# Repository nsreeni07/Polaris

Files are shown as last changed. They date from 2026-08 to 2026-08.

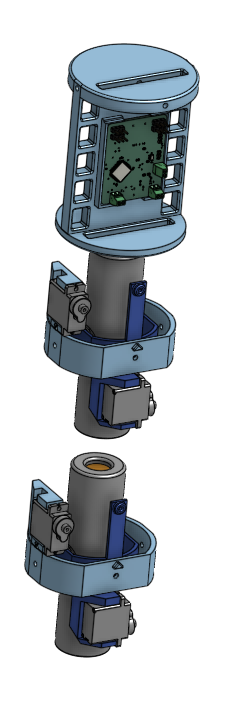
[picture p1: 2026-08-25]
Assets/Avionics and TVC.png

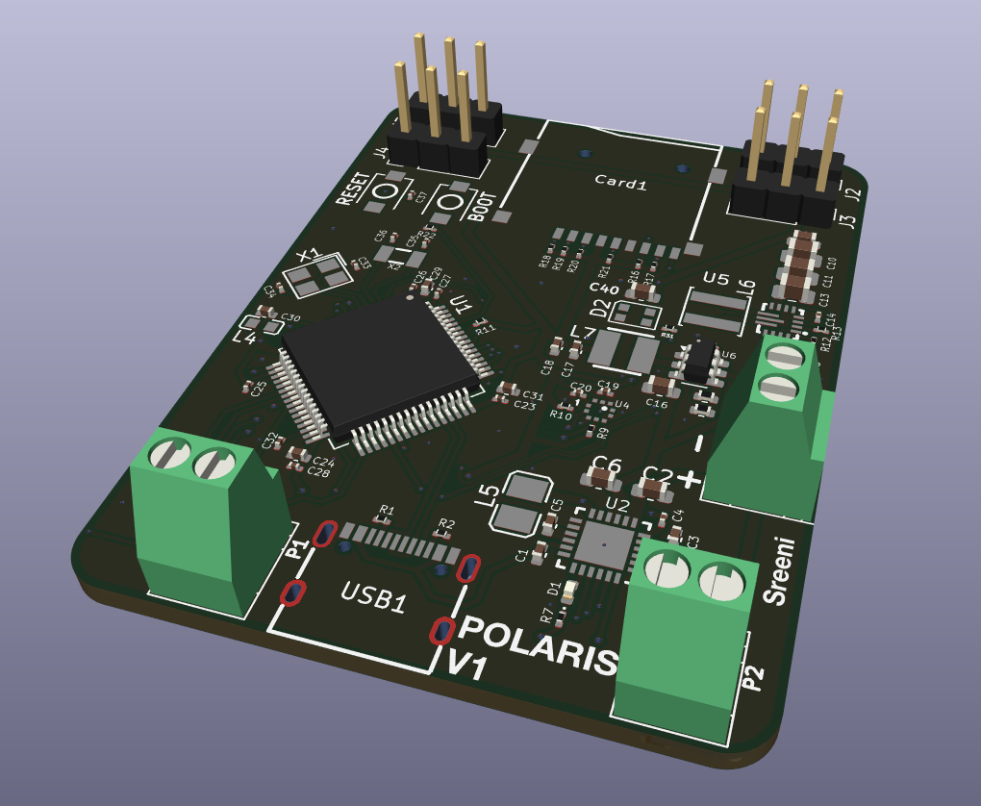
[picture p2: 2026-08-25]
Assets/Flight Computer PCB 3D.png

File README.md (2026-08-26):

# Polaris
Polaris is a two-stage amateur rocket with active thrust vector control(TVC) on the booster, along with a custom flight computer, ground support hardware, and firmware. 

# Why
Most amateur rocketry projects rely on passive stablization:fins,high-TWR motors. Polaris was built to go further. It has a ground lit booster stage with activle gimbal control instead of fins. Then after apogee the second motor lights hot-staging the booster stage off. Then paired with the flight computer the rocket stablizes and lands by itself

# Breakdown
Polaris is made up of 3 main subsystems
  1. Rocket-Airframe,Motors
  2. Flight Computer-Custom electronics and firmware that control the veichles orientation 
  3. Launchpad - the ground support equipment that holds, arms, and releases the rocket 

# Subsystems In Depth 
  1. Rocket
      - 2-Stage both with TVC 
      - 74cm length, 7.62 diameter, 662g dry mass
      - F-15 Motors 

  2. Flight Computer 
      - STM32F722RET6 MicroController
      - ICM-45686 IMU 
      - BMP580 Barometer
      - BQ25883 Battery Charger 
      - 4 channel servo PWM 
      - microSD Card for logging

  3. Launchpad 
      - ESP32 MicroController
      - 2 control arms that hold and release the rocket at liftoff 
      - 2 ESP32-CAM modules that record the launch 
      - RGB strip light and 4 2812 LEDs for pad status/lighting 
      - Water deluge system for pad deck 
      
  4. Firmware
  The flight computer is written from scratch organized into driver-level code (Core/) and mission appliccation logic (App/), covering the state machine, sensor fusion (Kalman filtering), pyro firing logic, servo/TVC Control, GPS parsing, DFU handoff, and the onboard     parameter store. Safety critical paths, particularly pyro firing, use redundant latching to prevent unintended actuation.  

  onshape Link: https://cad.onshape.com/documents/130dc36974a4df304d494706/w/43298f754d2d228858bc474d/e/d549df94310ea82951faf52f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
 # CAD 
Launchpad with Rocket
Rocket (2)
TVC Mount (2)

 # PCB


Flight Computer PCB 3D

|Category |Name |Price |Source |Purpose |FIELD6|Quantity|
|---|---|---|---|---|---|---|
|Electronics |ESP32 type-c FT232 |$4.60 |https://tinyurl.com/yhpx8n6v |MicroController for Launchpad | |1 |
| |ESP32 Expansion Board |$2.60 |https://tinyurl.com/23y7nzj4 |Expansion Board | |1 |
| |Esp32 Cam |$6.80 |https://tinyurl.com/4du8rxrx |Camera Board for recording | |1 |
| |WS2812 Breakout |$1.10 |https://tinyurl.com/47v776rm |Lights for Launchpad | |4 |
| |RGB Strip Light |$5.10 |https://tinyurl.com/364y65ux |Lights for Launchpad | |1 |
| |SG90 Servos |$9.00 |https://tinyurl.com/mr2s3xp6 |Servos for TVC and Launchpad Control Arms| |5 |
| |DRV8871 H-Bridge Motor Driver |$2.65 |https://tinyurl.com/32cf8wx4 |Motor Driver for Water Deluge System | |1 |
| |Jumper Wires |$4.70 |https://tinyurl.com/58u2vc35 |Wires | |1 |
| |22 AWG Wire |$3.39 |https://tinyurl.com/bdz5rad7 |Wires | |1 |
| |2.54mm Screw Terminal |$5.22 |https://tinyurl.com/4t54j69v |Screw Terminal | |2 |
| |JST XH2.54 Pitch 2 Pin Male Female|$2.29 |https://tinyurl.com/397bn54r |Battery Connector | |1 |
| |Micro SD Card |$7.70 |https://tinyurl.com/yx3v2jh6 |SD Card for Data logging | |1 |
| |OV5640 Camera |$5.47 |https://tinyurl.com/mv5eb5tb |Camera For recording | |1 |
| |DC Sumersible Pump |$2.43 |https://tinyurl.com/bp4uh89j |Water Pump | |1 |
| |2S Lipo |$4.60 |https://tinyurl.com/3x3pstst |Battery | |1 |
|Category |Name |Price |Source |Purpose | |Quantity|
|Hardware |3.00" Airframe Tubing |$14.16 |https://locprecision.com/products/cardboard-airframes?variant=39778656125119|Main Body Tube | |1 |
| |Hot Glue Sticks |$2.17 |https://tinyurl.com/yvwvy5t6 |Adhesive | |1 |
| |Epoxy |$3.42 |https://tinyurl.com/9rpxazkp |Adhesive | |1 |
| |Silicone Tube |$2.80 |https://tinyurl.com/3bzxhtnu |Tubing for Water Deluge System | |1 |
| |Header Pins |$3.63 |https://tinyurl.com/u3jnrvzz |Header Pins | |4 |
| | | | | | | |
|Below Totals contain Tax and Shipping | | | | | | |
| | | | | | | |
|LCSC |$105.00 |(PCB Parts| | | | |
|JLCPCB |$33.00 |(Bare PCB)| | | | |
|Aliexpress Total |$114.67 | | | | | |
|LOC Total |$28.30 | | | | | |
| | | | | | | |
| | | | | | | |
|Grant Total: |$280.97 | | | | | |

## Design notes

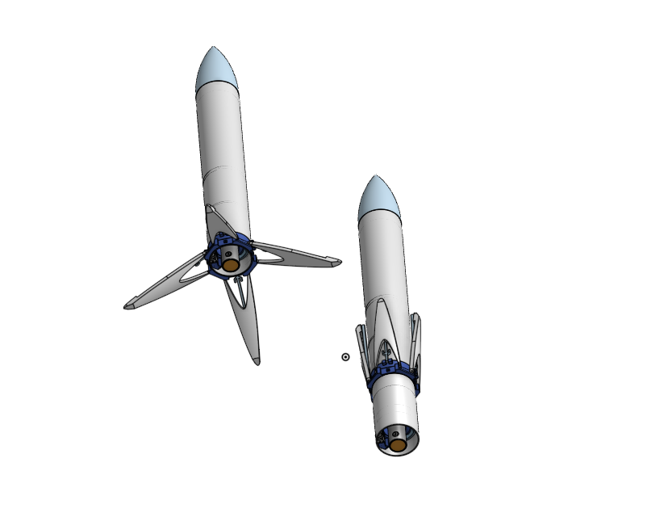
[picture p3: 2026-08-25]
Assets/Rocket.png

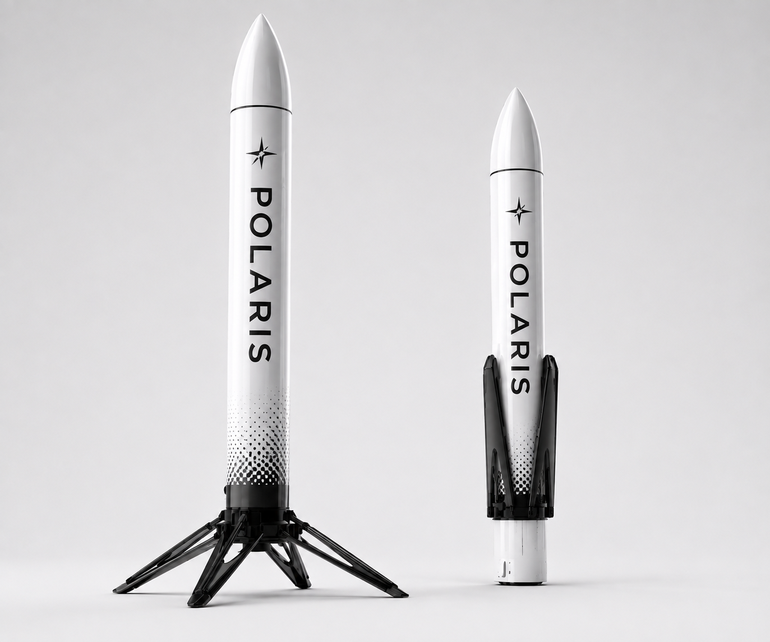
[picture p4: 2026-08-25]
Assets/Polaris Render.png

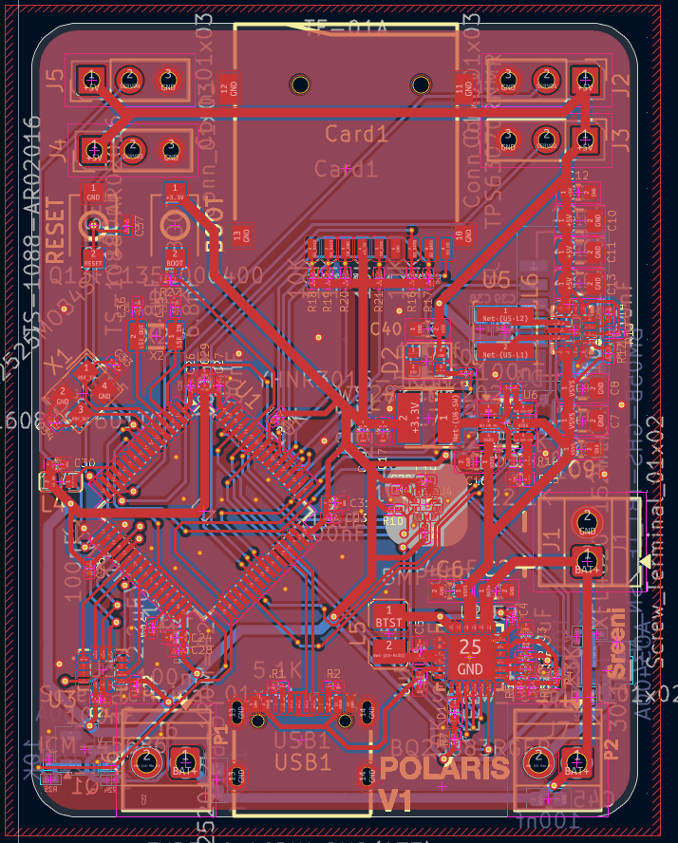
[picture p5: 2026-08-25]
Assets/Flight Computer PCB.png

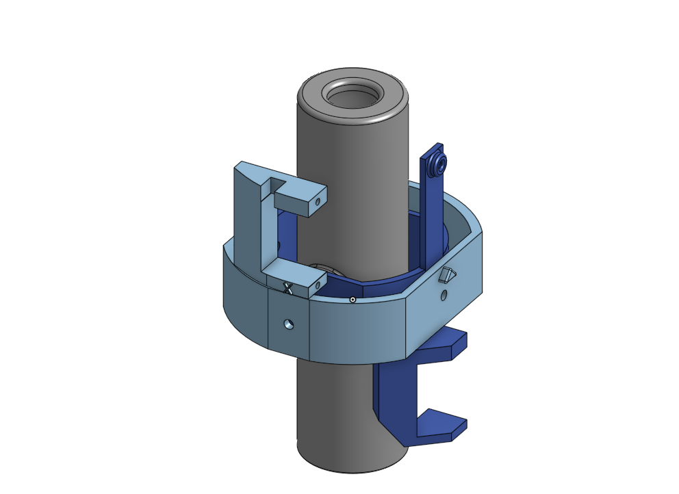
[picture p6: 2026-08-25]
Assets/TVC Mount.png

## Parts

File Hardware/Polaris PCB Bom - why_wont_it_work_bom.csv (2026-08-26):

Designator | Footprint | Quantity | Value | LCSC Part # | Link
BOOT, RESET | SW-SMD_L3.9-W3.0-P4.45 | 2 | TS-1088-AR02016 | C720477 | https://www.lcsc.com/product-detail/C720477.html?s_z=n_q_TS-1088-AR02016
C1, C28, C29, C30 | 402 | 4 | 1uF |  | https://www.lcsc.com/product-detail/C52923.html?s_z=n_q_CL05A105KA5NQNC
C10, C11, C13 | 805 | 3 | 22uF |  | https://www.lcsc.com/product-detail/C45783.html?s_z=n_q_CL21A226MAQNNNE
C12, C2, C38, C9 | 603 | 4 | 10uF |  | https://www.lcsc.com/product-detail/C19702.html?s_z=n_q_CL10A106KP8NNNC
C14, C15, C19, C20, C21, C22, C23, C24, C25, C26, C27, C37 | 201 | 12 | 100nF |  | https://www.lcsc.com/product-detail/C76934.html?s_z=n_q_GRM033R61A104KE15D
C16 | 603 | 1 | 2.2uF |  | https://www.lcsc.com/product-detail/C23630.html?s_z=n_q_CL10A225KO8NNNC
C17, C18 | 402 | 2 | 22uF |  | https://www.lcsc.com/product-detail/C415703.html?s_z=n_q_GRM155R60J226ME11D
C3, C31, C5 | 402 | 3 | 10uF |  | https://www.lcsc.com/product-detail/C15525.html?s_z=n_q_CL05A106MQ5NUNC
C32 | 201 | 1 | 2.2uF |  | https://www.lcsc.com/product-detail/C319184.html?s_z=n_q_2.2uF%252010V%2520X5R%25200201
C33, C34 | 201 | 2 | 20pF |  | https://www.lcsc.com/product-detail/C325444.html?s_z=n_q_CC0201JRNPO9BN200
C35, C36 | 201 | 2 | 6.8pF |  | https://www.lcsc.com/product-detail/C85916.html?s_z=n_q_GRM0335C1H6R8CA01D
C39, C40, C41, C45, C46 | 603 | 5 | 100nf |  | https://www.lcsc.com/product-detail/C14663.html?s_z=n_q_CC0603KRX7R9BB104
C4 | 201 | 1 | 47nF |  | https://www.lcsc.com/product-detail/C505465.html?s_z=n_q_CC0201KRX5R7BB473
C6 | 603 | 1 | 44uF |  | https://www.lcsc.com/product-detail/C3794525.html?s_z=n_q_44%2520uF
C7, C8 | 805 | 2 | 10uF |  | https://www.lcsc.com/product-detail/C440198.html?s_z=n_q_GRM21BR61H106KE43L
CARD1 | TF-SMD_TF-01A | 1 | TF-01A | C91145 | https://www.lcsc.com/product-detail/C2889258.html?s_z=n_q_TF-01A
D1 | 402 | 1 | LED |  | https://www.lcsc.com/product-detail/C965793.html?s_z=n_q_XL-1005UGC
D2 | LED_WS2812B-2020_PLCC4_2.0x2.0mm | 1 | WS2812B-2020 |  | https://www.aliexpress.us/item/3256812215746950.html?curPageLogUid=OtKo3ZWj1teS
J1, J6, J7 | TerminalBlock_Xinya_XY308-2.54-2P_1x02_P2.54mm_Horizontal | 3 | Screw_Terminal_01x02 |  | https://tinyurl.com/4t54j69v
J2, J3, J4, J5 | PinHeader_1x03_P2.54mm_Vertical | 4 | Conn_01x03 |  | https://tinyurl.com/u3jnrvzz
J8 | JST_BM05B-GHS-TBT_LF__SN__N_ | 1 | BM05B-GHS-TBT_LF__SN__N_ |  | https://tinyurl.com/397bn54r
L4 | L0603 | 1 | FCM1608KF-601T03 | C141723 | https://www.lcsc.com/product-detail/C141723.html?s_z=n_q_FCM1608KF-601T03
L5 | L2520 | 1 | DFE252012F-1R0M=P2 | C435392 | https://www.lcsc.com/product-detail/C435392.html?s_z=n_q_DFE252012F-1R0M%253DP2
L6 | IND-SMD_L4.0-W4.0-A | 1 | XFL4020-152MEC | C3033018 | https://www.lcsc.com/product-detail/C3033018.html?s_z=n_q_XFL4020-152MEC
L7 | IND-SMD_L3.0-W3.0 | 1 | YHNR3015-5R6M | C18236327 | https://www.lcsc.com/product-detail/C18236327.html?s_z=n_q_YHNR3015-5R6M
Q1, Q2 | SOT-23 | 2 | AO3400A |  | https://www.lcsc.com/product-detail/C20917.html?s_z=n_q_p_Transistor_FET%253AAO3400A
R1, R2 | 201 | 2 | 5.1K |  | https://www.lcsc.com/product-detail/C270344.html?s_z=n_q_0201WMF5101TEE
R10, R11, R12, R13, R16, R17, R18, R19, R20, R21, R22, R23, R26, R28, R30, R6, R7, R8, R9 | 201 | 19 | 10K |  | https://www.lcsc.com/product-detail/C7467266.html?s_z=n_q_FRC0201J103%2520TS
R14 | 402 | 1 | 100K |  | https://www.lcsc.com/product-detail/C25741.html?s_z=n_q_0402WGF1003TCE
R15 | 402 | 1 | 22.1K |  | https://www.lcsc.com/product-detail/C43473.html?s_z=n_q_0402WGF2212TCE
R24, R29 | 201 | 2 | 100K |  | https://www.lcsc.com/product-detail/C60491.html?s_z=n_q_t_100K
R25, R27, R31 | 201 | 3 | 100 |  | https://www.lcsc.com/product-detail/C304499.html?s_z=n_q_RC-01W1000FT
R3 | 201 | 1 | .383k |  | https://www.lcsc.com/product-detail/C166212.html?s_z=n_q_RTT013833FTH
R4 | 201 | 1 | 5.23K |  | https://www.lcsc.com/product-detail/C423492.html
R5 | 201 | 1 | 30.1K |  | https://www.lcsc.com/product-detail/C273278.html?s_z=n_q_RC0201FR-0730K1L
U1 | LQFP-64_10x10mm_P0.5mm | 1 | STM32F722RETx |  | https://www.lcsc.com/product-detail/C118207.html?s_z=n_q_STM32F722RET6
U2 | VFQFPN-24_L4.0-W4.0-P0.50-BL-EP2.8 | 1 | BQ25883RGER | C544362 | https://www.lcsc.com/product-detail/C544362.html?s_z=n_q_BQ25883RGER
U3 | LGA-14_L3.0-W2.5-P0.50-TL | 1 | ICM-45686 | C22459454 | https://www.lcsc.com/product-detail/C22459454.html?s_z=n_q_ICM-45686
U4 | LGA-10_L2.0-W2.0-P0.50-TL_BMP580 | 1 | BMP580 | C22391138 | https://www.lcsc.com/product-detail/C22391138.html?s_z=n_q_BMP580
U5 | VQFN-HR-15_L3.0-W2.5-P0.50-BL_TPS63070RNMR | 1 | TPS63070RNMR | C109322 | https://www.lcsc.com/product-detail/C109322.html?s_z=n_q_TPS63070RNMR
U6 | SOT-23-6 | 1 | LMR51430 |  | https://www.lcsc.com/product-detail/C5219261.html?s_z=n_q_LMR51430YFDDCR
USB1 | USB-C-SMD_TYPE-C-6PIN-2MD-073 | 1 | TYPE-C 16PIN 2MD(073) | C2765186 | https://www.lcsc.com/product-detail/C2765186.html?s_z=n_q_TYPE-C%252016PIN%25202MD%28073%29
X1 | CRYSTAL-SMD_4P-L3.2-W2.5-BL | 1 | X322525MOB4SI | C9006 | https://www.lcsc.com/product-detail/C9006.html?s_z=n_q_X322525MOB4SI
X2 | FC-135R_L3.2-W1.5 | 1 | Q13FC1350000400 | C32346 | https://www.lcsc.com/product-detail/C32346.html?s_z=n_q_Q13FC13500004

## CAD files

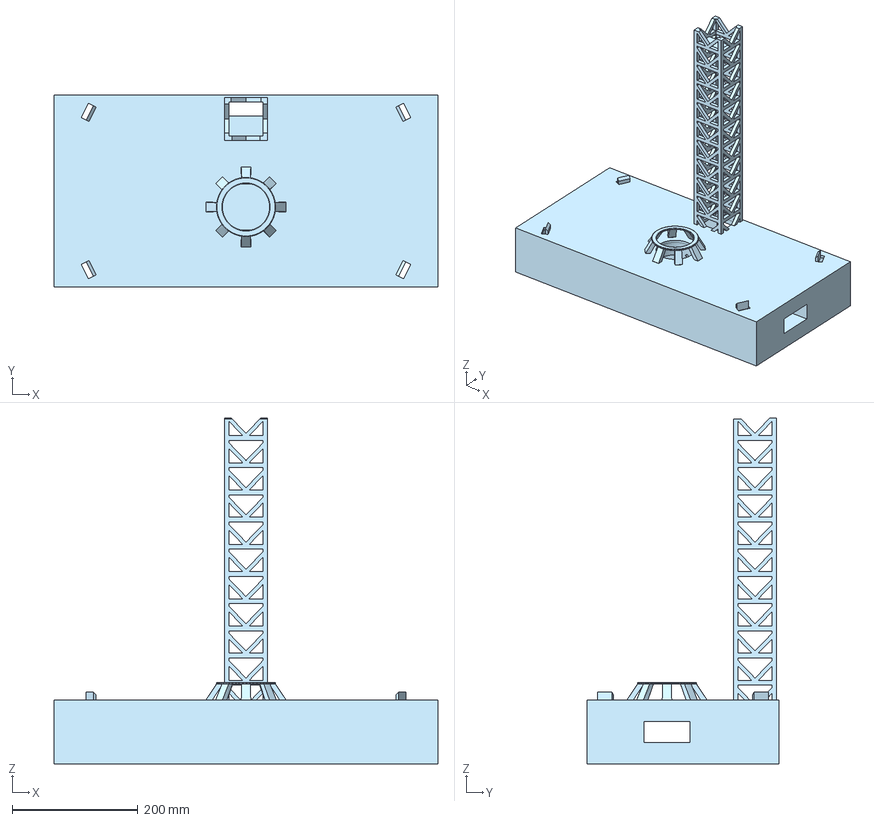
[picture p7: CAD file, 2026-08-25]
CAD/.step/Launchpad/Main Structure.step
609.6 x 304.8 x 549.2 mm

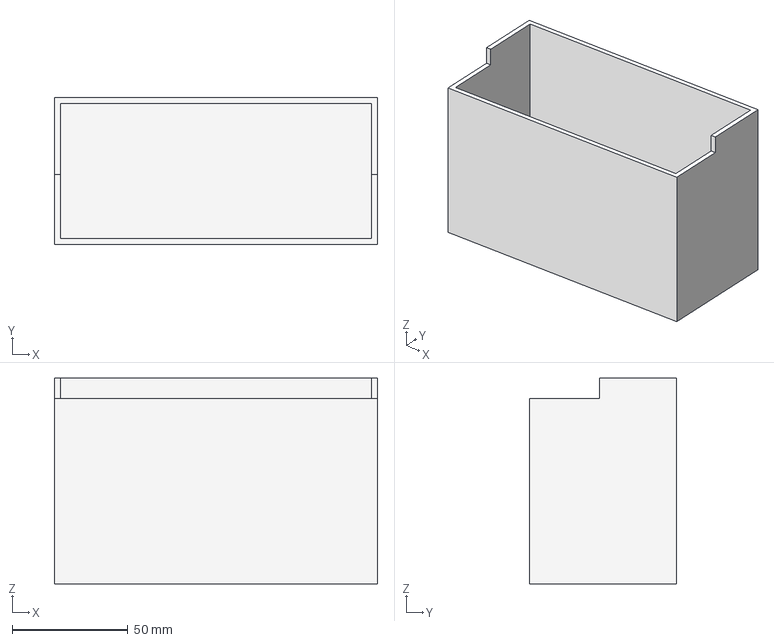
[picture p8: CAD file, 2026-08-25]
CAD/.step/Launchpad/Electronics Box.step
139.7 x 63.5 x 88.9 mm

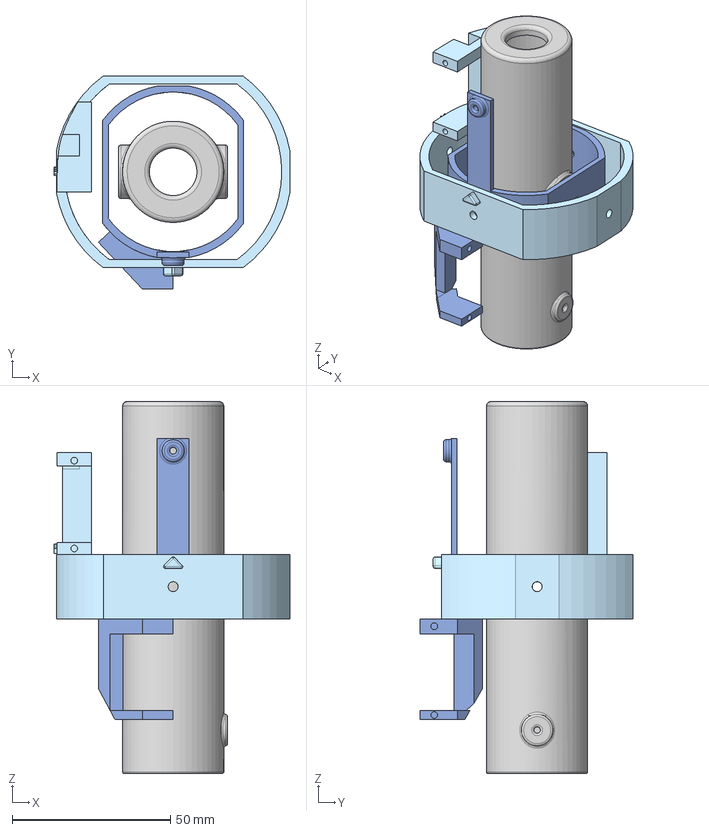
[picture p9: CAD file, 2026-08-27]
CAD/.step/Rocket/TVC Mount.step
74.4 x 67.3 x 117.5 mm

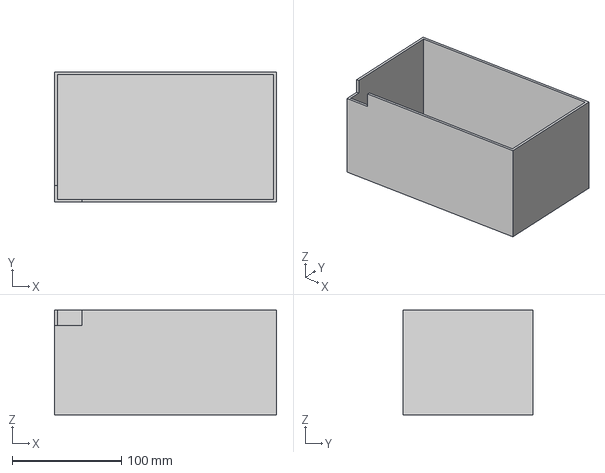
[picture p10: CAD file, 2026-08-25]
CAD/.step/Launchpad/Water Tank.step
203.2 x 119.4 x 96.0 mm

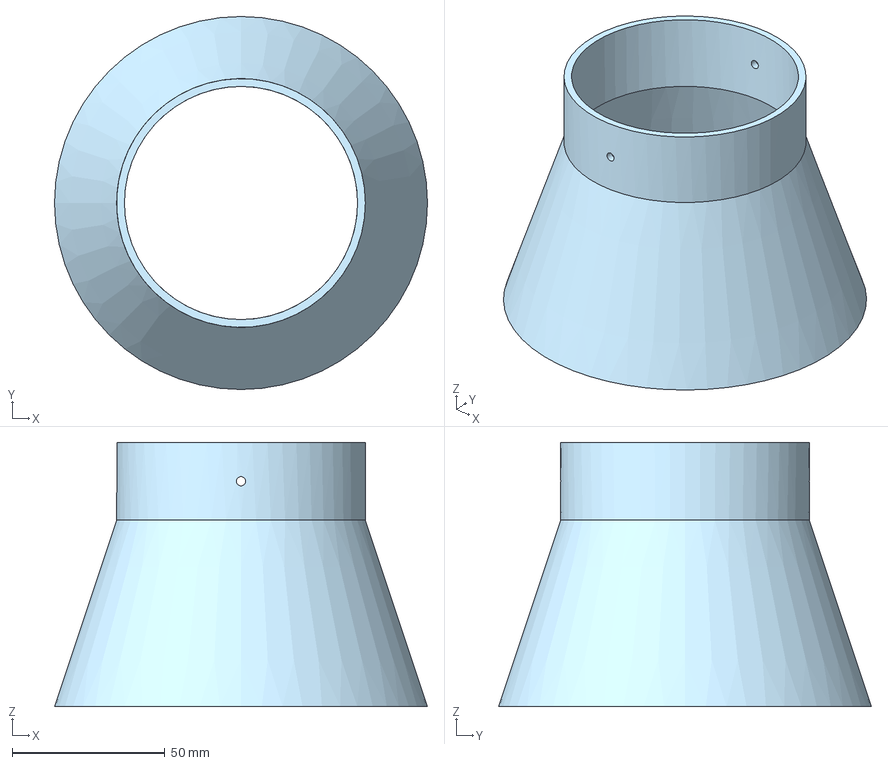
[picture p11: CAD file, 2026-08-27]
CAD/.step/Rocket/TVC Mount Test - Part 1.step
121.9 x 121.9 x 86.4 mm

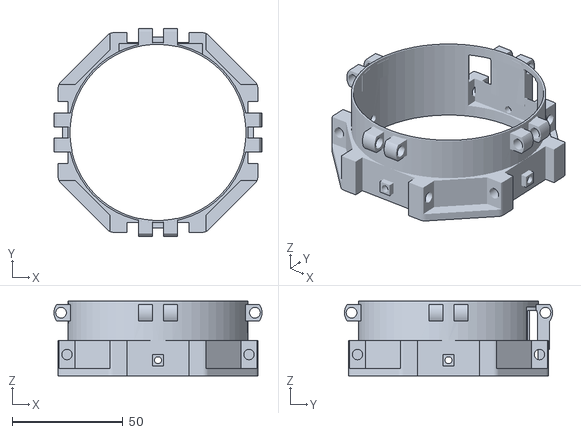
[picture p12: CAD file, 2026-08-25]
CAD/.stl/Rocket/Landing Mount.stl
93.7 x 93.7 x 33.8

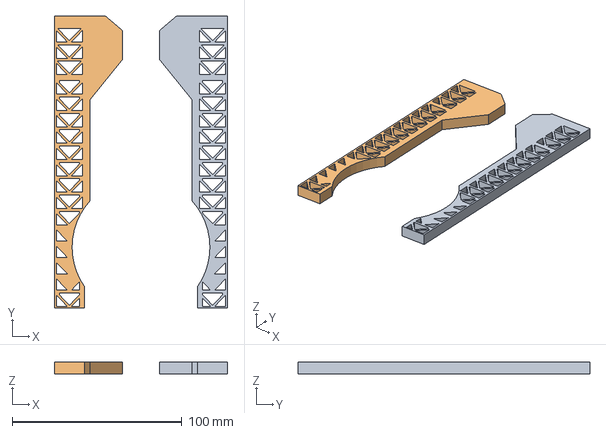
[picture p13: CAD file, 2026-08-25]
CAD/.step/Launchpad/Control Arms.step
102.3 x 172.2 x 7.11 mm

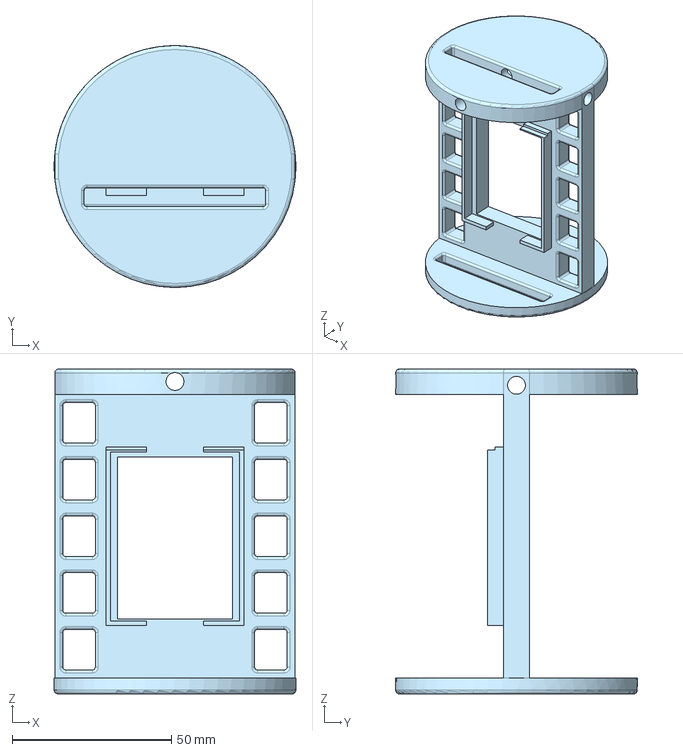
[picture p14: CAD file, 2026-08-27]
CAD/.step/Rocket/Avionics Bay.step
75.8 x 75.8 x 101.9 mm

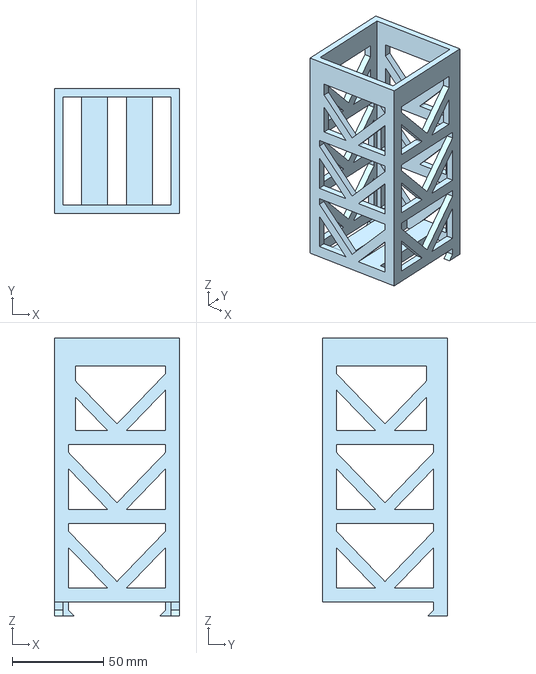
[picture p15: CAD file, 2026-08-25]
CAD/.step/Launchpad/Top Structure.step
68.6 x 68.6 x 152.4 mm

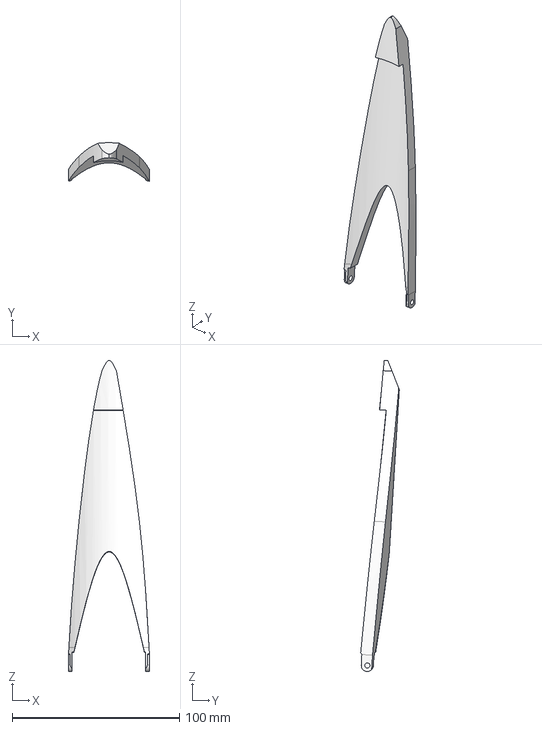
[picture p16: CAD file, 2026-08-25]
CAD/.step/Rocket/Landing Leg.step
48.3 x 23.1 x 185.8 mm

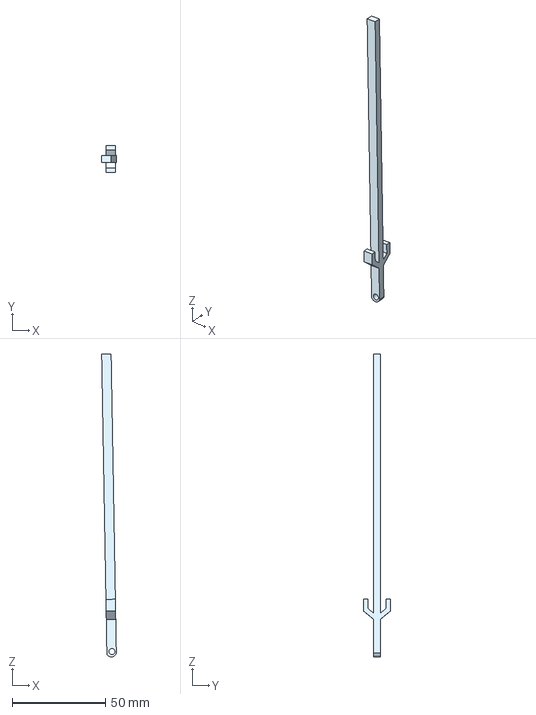
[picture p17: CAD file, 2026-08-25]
CAD/.step/Rocket/Landing Strut.step
7.87 x 14.5 x 162.2 mm

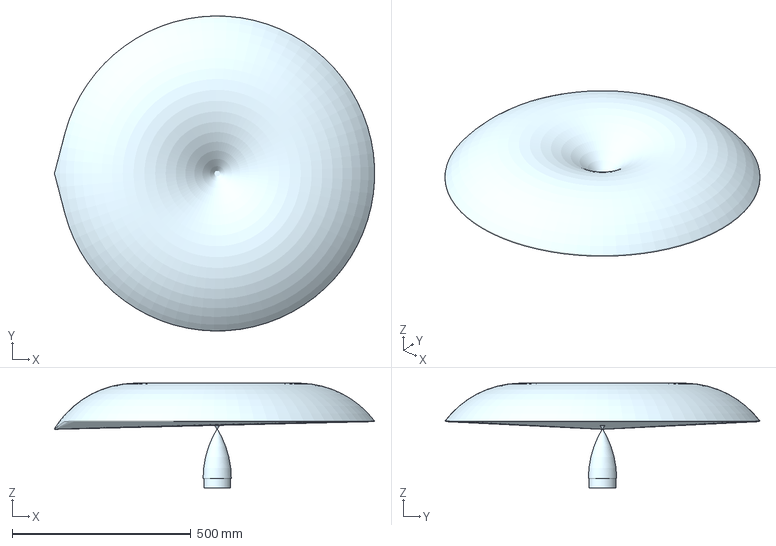
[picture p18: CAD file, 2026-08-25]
CAD/.step/Rocket/Nose Cone.step
895.6 x 881.2 x 292.6 mm

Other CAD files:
CAD/.stl/Rocket/TVC.stl
CAD/.stl/Launchpad/Control Arms.stl
CAD/.stl/Launchpad/Electronics Box.stl
CAD/.stl/Launchpad/Main Structure.stl
CAD/.stl/Launchpad/Top Structure.stl
CAD/.stl/Launchpad/Water Tank.stl
CAD/.stl/Rocket/Avionics Bay.stl
CAD/.stl/Rocket/Landing Leg.stl
CAD/.stl/Rocket/Nose Cone.stl
CAD/.stl/Rocket/TVC Mount Test - Part 1.stl

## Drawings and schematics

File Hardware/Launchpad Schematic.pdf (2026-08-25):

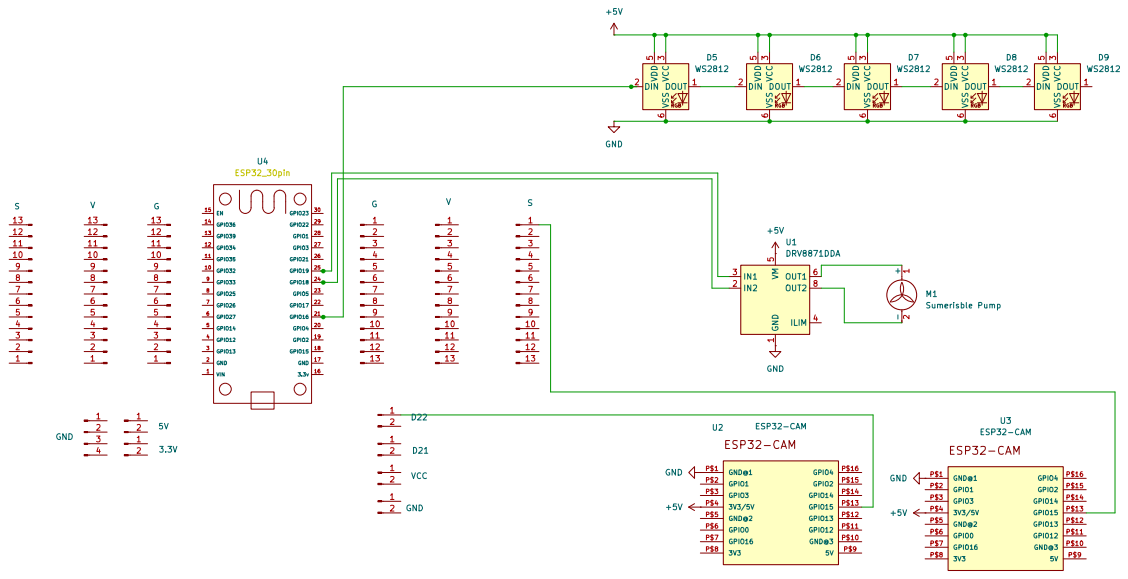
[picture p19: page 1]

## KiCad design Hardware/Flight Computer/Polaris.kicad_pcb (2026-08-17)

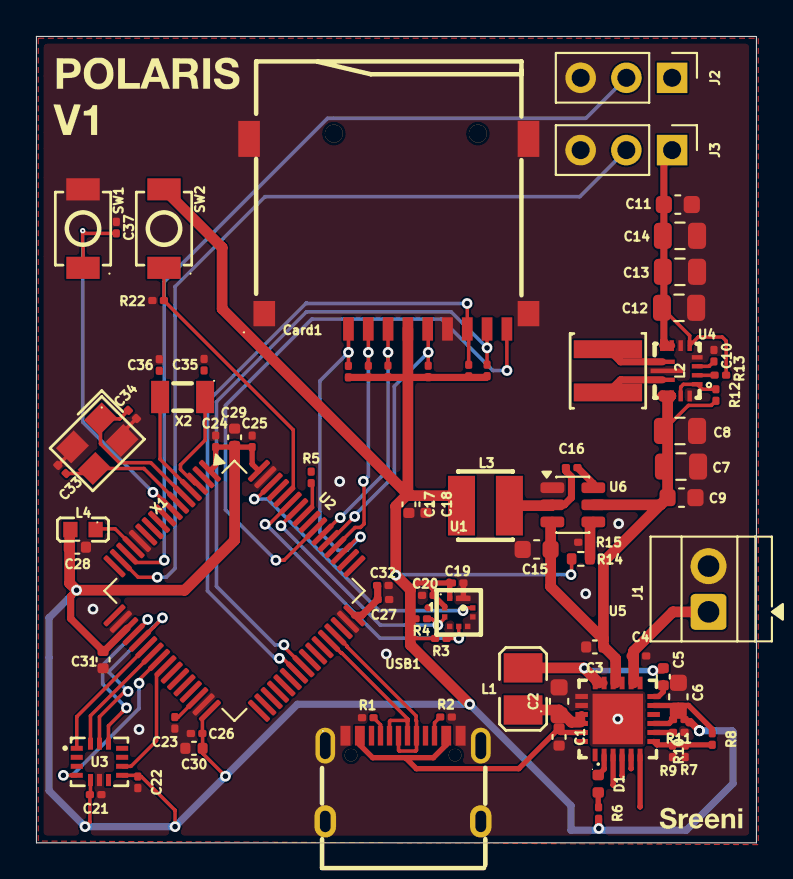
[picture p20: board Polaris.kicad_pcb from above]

Board: 2 copper layers, 40.0 x 44.8 mm, 79 parts (0 on the bottom side), 55 nets.

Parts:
C1, C29, C30, C31: 1uF; C_0402_1005Metric
C2, C6, C9, C11: 10uF; C_0603_1608Metric
C3: 44uF; C_0402_1005Metric
C4, C32: 10uF; C_0201_0603Metric
C5: 47nF; C_0402_1005Metric
C7, C8: 10uF; C_0805_2012Metric
C10, C16, C19, C20, C21, C22, C24, C25, C26, C27, C37: 100nF; C_0201_0603Metric
C12, C13, C14: 22uF; C_0805_2012Metric
C15: 2.2uF; C_0603_1608Metric
C17, C18: 22uF; C_0402_1005Metric
C23: 2.2uF; C_0201_0603Metric
C28: 100nF; C_0402_1005Metric
C33, C34: 20pF; C_0201_0603Metric
C35, C36: 6.8pF; C_0201_0603Metric
Card1: TF-01A; TF-SMD_TF-01A
D1: LED; LED_0402_1005Metric
J1: Screw_Terminal_01x02; TerminalBlock_Xinya_XY308-2.54-2P_1x02_P2.54mm_Horizontal
J2, J3: Conn_01x03; PinHeader_1x03_P2.54mm_Vertical
L1: 1uH; L2520
L2: 1.5uH; IND-SMD_L4.0-W4.0-A
L3: 5.6uH; IND-SMD_L3.0-W3.0
L4: FCM1608KF-601T03; L0603
R1, R2: 5.1k; R_0201_0603Metric
R3, R4, R5, R6, R7, R11, R12, R13, R16, R17, R18, R19, R20, R21, R22: 10K; R_0201_0603Metric
R8: 5.23K; R_0201_0603Metric
R9: 30.1K; R_0201_0603Metric
R10: 383; R_0201_0603Metric
R14: 100K; R_0402_1005Metric
R15: 22.1K; R_0201_0603Metric
SW1, SW2: TS-1088-AR02016; SW-SMD_L3.9-W3.0-P4.45
U1: BMP580; LGA-10_L2.0-W2.0-P0.50-TL_BMP580
U2: STM32F722RETx; LQFP-64_10x10mm_P0.5mm
U3: ICM-45686; LGA-14_L3.0-W2.5-P0.50-TL
U4: TPS63070RNMR; VQFN-15_L3.0-W2.5-P0.50-BL
U5: BQ25883RGER; VFQFPN-24_L4.0-W4.0-P0.50-BL-EP2.8
U6: LMR51430; SOT-23-6
USB1: TYPE-C 16PIN 2MD; USB-C-SMD_TYPE-C-16PIN-2MD-073
X1: X322525MOB4SI; CRYSTAL-SMD_4P-L3.2-W2.5-BL
X2: Q13FC1350000400; FC-135R_L3.2-W1.5

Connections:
+3.3V: C17.1, C18.1, C19.1, C20.1, C21.1, C22.1, C24.1, C25.1, C26.1, C27.1, C28.1, C29.1, C30.1, C31.1, C32.1, Card1.4 (VDD), L3.2, L4.2, R3.1, R4.1, R5.1, R6.2, R11.1, R14.1, R16.1, R17.1, R18.1, R19.1, R20.1, R21.1, SW2.1, U1.1 (VDDIO), U1.10 (VDD), U2.1 (VBAT), U2.19 (VDD), U2.32 (VDD), U2.48 (VDD), U2.64 (VDD), U3.5 (VDDIO), U3.8 (VDD)
+5V: C11.1, C12.1, C13.1, C14.1, J2.1, J3.1, R13.2, U4.5 (FB), U4.7 (Vout), U4.8 (Vout)
/BMP_INT: U1.7 (INT), U2.62 (PB9)
/BOOT: R22.1, SW2.2, U2.60 (BOOT0)
/BQ_CE: U2.61 (PB8), U5.3 (~CE)
/BQ_INT: R5.2, U2.57 (PB5), U5.6 (~INT)
/BQ_PG: R11.2, U5.9 (~PG)
/BTST: C5.1, L1.2, U5.17 (SW), U5.18 (SW)
/HSE_IN: C34.1, U2.5 (PH0), X1.1 (OSC1)
/HSE_OUT: C33.1, U2.6 (PH1), X1.3 (OSC2)
/I2C_SCL: R4.2, U1.2 (SCK), U2.58 (PB6), U5.5 (SCL)
/I2C_SDA: R3.2, U1.4 (SDI), U2.59 (PB7), U5.4 (SDA)
/ICM_CS: U2.20 (PA4), U3.12 (AP_CS)
/ICM_INT1: U2.24 (PC4), U2.41 (PA8), U3.4 (INT1/INT)
/ICM_INT2: U2.25 (PB0), U2.42 (PA9), U3.9 (INT2/FSYNC/CLKIN)
/ICM_SCK: U2.21 (PA5), U3.13 (AP_SCL/AP_SCLK)
/ICM_SDI: U2.23 (PA7), U3.14 (AP_SDA/AP_SDIO/AP_SDI)
/ICM_SDO: U2.22 (PA6), U3.1 (AP_SDO/AP_AD0)
/LSE_IN: C35.1, U2.3 (PC14), X2.1
/LSE_OUT: C36.1, U2.4 (PC15), X2.2
/RESET: C37.2, SW1.2, U2.7 (NRST)
/SD_CD: Card1.9 (CD), U2.55 (PB3)
/SD_CLK: Card1.5 (CLK(SCLK)), R21.2, U2.53 (PC12)
/SD_CMD: Card1.3 (CMD(DI)), R16.2, U2.54 (PD2)
/SD_DAT0: Card1.7 (DAT0(D0)), R20.2, U2.39 (PC8)
/SD_DAT1: Card1.8 (DAT1(RSV)), R19.2, U2.40 (PC9)
/SD_DAT2: Card1.1 (DAT2(RSV)), R18.2, U2.51 (PC10)
/SD_DAT3: Card1.2 (CDDAT3(CS)), R17.2, U2.52 (PC11)
/SERVO1: J2.2, U2.14 (PA0)
/SERVO2: J3.2, U2.15 (PA1)
/USB_DN: U2.44 (PA11), USB1.A7 (Dn1), USB1.B7 (Dn2)
/USB_DP: U2.45 (PA12), USB1.A6 (Dp1), USB1.B6 (Dp2)
BAT+: C4.1, J1.1, U5.13 (BAT), U5.14 (BAT)
GND: C1.2, C2.2, C3.2, C4.2, C6.2, C7.2, C8.2, C9.2, C10.1, C11.2, C12.2, C13.2, C14.2, C15.2, C17.2, C18.2, C19.2, C20.2, C21.2, C22.2, C23.2, C24.2, C25.2, C26.2, C27.2, C28.2, C29.2, C30.2, C31.2, C32.2, C33.2, C34.2, C35.2, C36.2, C37.1, Card1.6 (VSS), Card1.10 (GND), Card1.11 (GND), Card1.12 (GND), Card1.13 (GND), J1.2, J2.3, J3.3, R1.1, R2.1, R7.2, R9.2, R10.1, R15.2, R22.2, SW1.1, U1.3 (VSS), U1.5 (SDO), U1.6 (CSB), U1.8 (VSS), U1.9 (VSS), U2.12 (VSSA), U2.18 (VSS), U2.31 (VSS), U2.47 (VSS), U2.63 (VSS), U3.6 (GND), U4.4 (GND), U4.6 (FB2), U4.10 (PGND), U4.15 (Vsel), U5.19 (GND), U5.20 (GND), U5.25 (EP), U6.1 (GND), USB1.13 (EH), USB1.14 (EH), USB1.A1B12 (GND), USB1.B1A12 (GND), X1.2 (GND), X1.4 (GND)
unnamed: C2.1, L1.1, U5.21 (PMID), U5.22 (PMID)
unnamed: D1.2 (A), R6.1
unnamed: D1.1 (K), U5.2 (STAT)
unnamed: C23.1, U2.30 (VCAP_1)
unnamed: L4.1, U2.13 (VDDA)
unnamed: R12.1, U4.1 (PS/SYNC), U4.14 (EN)
unnamed: L2.2, U4.11 (L1)
unnamed: L2.1, U4.9 (L2)
unnamed: R13.1, U4.2 (PG)
unnamed: C10.2, U4.3 (Vaux)
unnamed: C5.2, U5.12 (BTST)
unnamed: R10.2, U5.8 (ILIM)
unnamed: R7.1, R8.2, R9.1, U5.7 (TS)
unnamed: C16.2, U6.6 (CB)
unnamed: R14.2, R15.1, U6.4 (FB)
unnamed: C16.1, L3.1, U6.2 (SW)
unnamed: R1.2, USB1.A5 (CC1)
unnamed: R2.2, USB1.B5 (CC2)
VBUS: C1.1, U5.23 (VBUS), USB1.A4B9 (VBUS), USB1.B4A9 (VBUS)
VREGN: C6.1, R8.1, U5.11 (REGN)
VSYS: C3.1, C7.1, C8.1, C9.1, C15.1, R12.2, U4.12 (Vin), U4.13 (Vin), U5.15 (SYS), U5.16 (SYS), U6.3 (VIN), U6.5 (EN)

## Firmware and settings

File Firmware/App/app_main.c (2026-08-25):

/* no way jose */
#include "board.h"
#include "app_config.h"
#include "app_types.h"
#include "app_main.h"

#include "imu_icm45686.h"
#include "baro_bmp580.h"
#include "servo.h"
#include "pyro.h"
#include "ahrs.h"
#include "kalman.h"
#include "tvc_control.h"
#include "flight_state.h"
#include "datalog.h"
#include "param_store.h"
#include "safety.h"

#if ENABLE_CHARGER
#include "charger_bq25883.h"
#endif
#if ENABLE_GPS
#include "gps_nmea.h"
#endif
#if ENABLE_STATUS_LED
#include "status_led.h"
#endif

static uint32_t s_last_ctrl_ms, s_last_baro_ms, s_last_cont_ms, s_last_flush_ms;
#if ENABLE_CHARGER
static uint32_t s_last_charger_ms;
static uint16_t s_last_vbat_mv;
#endif
#if ENABLE_STATUS_LED
static uint32_t s_last_led_ms;
#endif

void app_init(void)
{
    pyro_init();

#if ENABLE_STATUS_LED
    led_init();
    led_show_state(ST_INIT);
#endif

    servo_init();
    servo_center_all();

    int imu_rc = imu_init();
    int baro_rc = baro_init();
#if ENABLE_CHARGER
    charger_init();
#endif
#if ENABLE_GPS
    gps_init();
#endif

    params_t params;
    param_load(&params);
    tvc_set_gains(params.tvc_kp, params.tvc_ki, params.tvc_kd);

    ahrs_init();
    kalman_init();
    tvc_init();

    if (imu_rc == 0)
        imu_calibrate_gyro();
    if (baro_rc == 0)
        baro_zero();

    int log_rc = datalog_init();
    (void)log_rc;

    safety_init();   /* starts IWDG - call last */

    fsm_init();
#if ENABLE_STATUS_LED
    led_show_state(ST_GROUND_IDLE);
#endif
}

static void run_control_tick(void)
{
    if (!g_imu_data_ready)
        return;

    static uint32_t last_t_ms = 0;
    imu_sample_t s;
    if (imu_read(&s) != 0)
        return;

    float dt_s = (last_t_ms == 0) ? (1.0f / CTRL_HZ) : (float)(s.t_ms - last_t_ms) / 1000.0f;
    last_t_ms = s.t_ms;

    ahrs_update(&s, dt_s);

    float axial_g;
    switch (ARM_UP_AXIS) {
        case 0: axial_g = s.ax; break;
        case 1: axial_g = s.ay; break;
        default: axial_g = s.az; break;
    }
    axial_g *= ARM_UP_SIGN;
    float axial_accel_ms2 = (axial_g - 1.0f) * 9.80665f;
    kalman_predict(axial_accel_ms2, dt_s);

    fsm_tick(&s, dt_s);

    wdg_refresh();
}

void app_loop(void)
{
    for (;;) {
        uint32_t now = HAL_GetTick();

        if ((now - s_last_ctrl_ms) >= (1000u / CTRL_HZ)) {
            s_last_ctrl_ms = now;
            run_control_tick();
        }

        if ((now - s_last_baro_ms) >= (1000u / BARO_HZ)) {
            s_last_baro_ms = now;
            float alt, temp;
            if (baro_read(&alt, &temp) == 0)
                kalman_correct_baro(alt);
        }

        if ((now - s_last_cont_ms) >= (1000u / CONT_HZ)) {
            s_last_cont_ms = now;
            /* ground-status display only; pyro_fire() re-checks continuity itself */
        }

#if ENABLE_CHARGER
        if ((now - s_last_charger_ms) >= (1000u / CHARGER_HZ)) {
            s_last_charger_ms = now;
            charger_read_vbat_mv(&s_last_vbat_mv);
            g_fsm.snapshot.vbat_mv = s_last_vbat_mv;
        }
#endif

#if ENABLE_STATUS_LED
        if ((now - s_last_led_ms) >= (1000u / LED_HZ)) {
            s_last_led_ms = now;
            led_show_state(fsm_get_state());
        }
#endif

        if ((now - s_last_flush_ms) >= LOG_FLUSH_MS) {
            s_last_flush_ms = now;
            datalog_flush();
        }

#if ENABLE_GPS
        gps_poll();
#endif

        static uint32_t last_log_ms = 0;
        if ((now - last_log_ms) >= (1000u / LOG_RATE_HZ)) {
            last_log_ms = now;
            log_record_t rec = {0};
            rec.magic = LOG_RECORD_MAGIC;
            rec.state = (uint8_t)g_fsm.state;
            rec.t_ms = g_fsm.snapshot.t_ms;
            rec.ax = g_fsm.snapshot.imu.ax;
            rec.ay = g_fsm.snapshot.imu.ay;
            rec.az = g_fsm.snapshot.imu.az;
            rec.gx = g_fsm.snapshot.imu.gx;
            rec.gy = g_fsm.snapshot.imu.gy;
            rec.gz = g_fsm.snapshot.imu.gz;
            rec.alt_m = g_fsm.snapshot.alt.alt_m;
            rec.vel_ms = g_fsm.snapshot.alt.vel_ms;
            rec.pitch_deg = g_fsm.snapshot.att.pitch_deg;
            rec.yaw_deg = g_fsm.snapshot.att.yaw_deg;
            rec.vbat_mv = g_fsm.snapshot.vbat_mv;
            datalog_write(&rec);
        }
    }
}

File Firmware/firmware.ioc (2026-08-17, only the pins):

Mcu.UserName=STM32F722RETx
PA0-WKUP.Signal=S_TIM2_CH1_ETR
PA1.Signal=S_TIM2_CH2
PA11.Signal=USB_OTG_FS_DM
PA12.Signal=USB_OTG_FS_DP
PA4.Signal=SPI1_NSS
PA5.Signal=SPI1_SCK
PA6.Signal=SPI1_MISO
PA7.Signal=SPI1_MOSI
PB0.GPIO_Label=ICM_INT2
PB0.Signal=GPXTI0
PB3.GPIO_Label=SD_CS
PB3.Signal=GPIO_Input
PB5.GPIO_Label=BQ_INT
PB5.Signal=GPXTI5
PB6.Signal=I2C1_SCL
PB7.Signal=I2C1_SDA
PB8.GPIO_Label=BQ_CE
PB8.Signal=GPIO_Output
PB9.GPIO_Label=BMP_INT
PB9.Signal=GPXTI9
PC10.Signal=SDMMC1_D2
PC11.Signal=SDMMC1_D3
PC12.Signal=SDMMC1_CK
PC14-OSC32_IN.Signal=RCC_OSC32_IN
PC15-OSC32_OUT.Signal=RCC_OSC32_OUT
PC4.GPIO_Label=ICM_INT1
PC4.Signal=GPXTI4
PC8.Signal=SDMMC1_D0
PC9.Signal=SDMMC1_D1
PD2.Signal=SDMMC1_CMD
PH0-OSC_IN.Signal=RCC_OSC_IN
PH1-OSC_OUT.Signal=RCC_OSC_OUT

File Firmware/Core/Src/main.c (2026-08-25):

#include "main.h"
#include "app_main.h"

int main(void)
{
    HAL_Init();
    SystemClock_Config();

    MX_GPIO_Init();
    MX_SPI1_Init();
    MX_I2C1_Init();
    MX_TIM2_Init();
    MX_SDMMC1_SD_Init();
#if ENABLE_GPS
    MX_USART6_UART_Init();
#endif


    app_init();
    app_loop();   /* never returns */
}

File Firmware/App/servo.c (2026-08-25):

/* TIM2, 4-channel PWM. .ioc currently only configures CH1/CH2 - add
 * CH3 (PA2) and CH4 (PA3) there before this will drive all 4 servos. */
#include "servo.h"
#include "app_config.h"
#include "board.h"

static const uint32_t s_channels[SERVO_COUNT] = {
    TIM_CHANNEL_1, TIM_CHANNEL_2, TIM_CHANNEL_3, TIM_CHANNEL_4
};

int servo_init(void)
{
    for (int i = 0; i < SERVO_COUNT; i++)
        if (HAL_TIM_PWM_Start(&htim2, s_channels[i]) != HAL_OK)
            return -1;
    return 0;
}

void servo_set_us(int ch, uint16_t pulse_us)
{
    if (ch < 0 || ch >= SERVO_COUNT)
        return;
    if (pulse_us < SERVO_MIN_US) pulse_us = SERVO_MIN_US;
    if (pulse_us > SERVO_MAX_US) pulse_us = SERVO_MAX_US;
    __HAL_TIM_SET_COMPARE(&htim2, s_channels[ch], pulse_us);
}

void servo_set_deg(int ch, float deg)
{
    if (deg > 90.0f) deg = 90.0f;
    if (deg < -90.0f) deg = -90.0f;
    servo_set_us(ch, (uint16_t)(SERVO_CENTER_US + deg * SERVO_US_PER_DEG));
}

void servo_center_all(void)
{
    for (int i = 0; i < SERVO_COUNT; i++)
        servo_set_us(i, SERVO_CENTER_US);
}

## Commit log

2026-08-10 Create PCB
2026-08-11 Rename Firmware/firmware.ioc to Firmware/STM32 Firmware/firmware.ioc
2026-08-11 Rename Firmware/STM32 Firmware/firmware.ioc to Firmware/firmware.ioc
2026-08-17 Rename Polaris.kicad_sch to Hardware/Flight Computer/Polaris.kicad_sch
    [Polaris.kicad_sch]
2026-08-25 Rename CAD/Main Structure.step to CAD/.step/Main Structure.step
    [Main Structure.step]
2026-08-25 Rename CAD/Top Structure.stl to CAD/.stl/Top Structure.stl
    [Top Structure.stl]
2026-08-25 Add Control Arms.step file to Launchpad directory
    [Control Arms.step]
2026-08-25 Add Main Structure.step to Launchpad directory
    [Main Structure.step]
2026-08-25 Rename CAD/.step/Top Structure.step to CAD/.step/Launchpad/Top Structure.step
    [Top Structure.step]
2026-08-25 Rename CAD/.step/Water Tank.step to CAD/.step/Launchpad/Water Tank.step
    [Water Tank.step]
2026-08-25 Add Landing Mount.step to Rocket directory
    [Landing Mount.step]
2026-08-25 Add Nose Cone.step to Rocket directory
    [Nose Cone.step]
2026-08-25 Rename CAD/.stl/Top Structure.stl to CAD/.stl/Launchpad/Top Structure.stl
    [Top Structure.stl]
2026-08-25 Rename CAD/.stl/Landing Mount.stl to CAD/.stl/Rocket/Landing Mount.stl
    [Landing Mount.stl]
2026-08-25 Fix formatting of CAD link in README.md
2026-08-25 Fix CAD link formatting in README.md
2026-08-25 Fix CAD link formatting in README
    Updated the CAD link format in the README.
2026-08-26 Add PCB section with images to README
    Added PCB section with images to README.
2026-08-27 Rename CAD/.step/TVC Mount Test - Part 1.step to CAD/.step/Rocket/TVC Mount Test - Part 1.step
    [TVC Mount Test - Part 1.step]
